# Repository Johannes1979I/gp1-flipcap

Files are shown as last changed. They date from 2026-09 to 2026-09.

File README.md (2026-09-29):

# GP1 FlipCap V6

Tappo antipolvere motorizzato per telescopi newtoniani, comandato da
**INDI / Ekos**. Un motore e un braccio: aprendosi il tappo ruota di **270°**,
scavalca la scatola e si **posa sul tubo**, così il vento non lo fa vibrare.
Riduttore ed elettronica stanno in un'unica scatola stampata, fissata al tubo
con due cinghie a strappo.

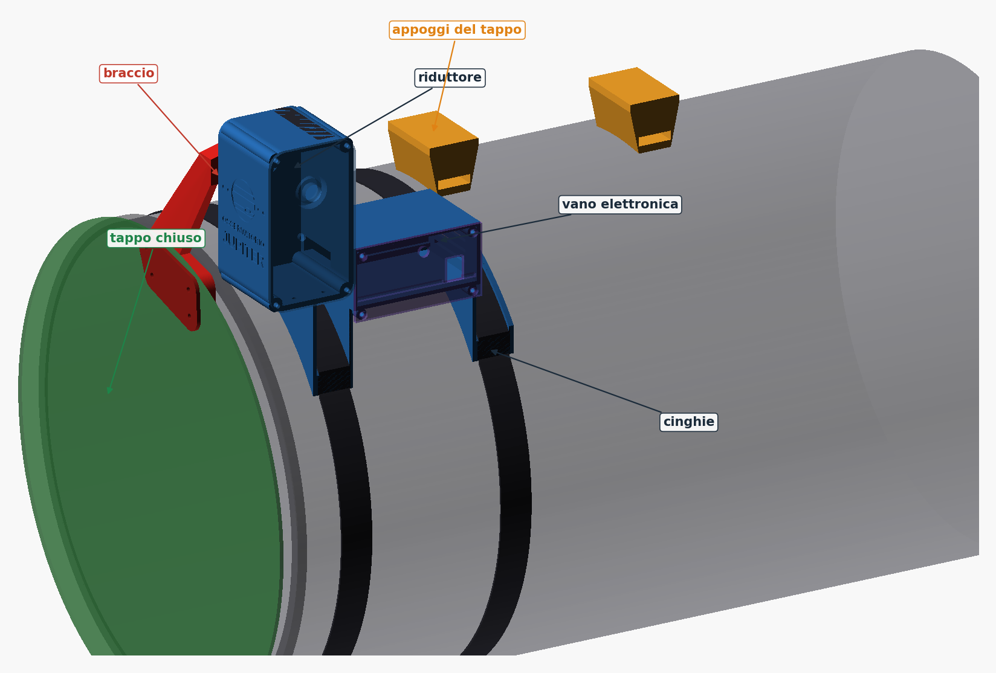
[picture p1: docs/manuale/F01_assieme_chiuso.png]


📘 **[MANUALE_MONTAGGIO_V6.pdf](MANUALE_MONTAGGIO_V6.pdf)**: dal primo pezzo
stampato fino alla configurazione di Ekos, passo per passo, per chi costruisce
da zero.

---

## Caratteristiche

| | |
|---|---|
| Motore | 28BYJ-48 5 V + scheda ULN2003 |
| Riduzione | riduttore interno del 28BYJ + treno stampato 15:1 (modulo 0,8) |
| Corsa | 270°, circa 55 secondi; da aperto il tappo appoggia su due supporti sul tubo |
| Albero di uscita | acciaio Ø6 × 100 mm su due 626ZZ, bloccato da distanziali stampati |
| Finecorsa | 2 sensori Hall A3144 su piastra registrabile, magnete 6×3 su bandierina |
| Elettronica | Arduino Nano + ULN2003 + LM2596 nel vano della scatola, su un vassoio |
| Alimentazione | 12 V del setup; USB verso il PC |
| Fissaggio | due selle e due cinghie a strappo da 25 mm |
| Protocollo | Alnitak Remote Dust Cover, product ID 98 (`indi_flipflat`) |
| Default | tubo Ø362 mm (Sky-Watcher Quattro 300), tappo Ø374 mm, tutto parametrico |
| Stampa | 14 file, circa 600 cm³ di PETG o ASA; più 2 assi di prova facoltativi |
| Logo | Osservatorio Jupiter, inciso sulla faccia anteriore della scatola (`logo=false` per toglierlo) |

Non è un pannello per i flat: copre e scopre, non ha una luce.

## Per cominciare

1. Misura il diametro del tuo tubo (circonferenza ÷ π). Se non è 362 mm,
   rigenera `housing` e `cap_rest` (appendice E del manuale).
2. Stampa i pezzi in `stl/`: sono già orientati per la stampa. PETG o ASA,
   **non PLA**.
3. Procurati viteria, cuscinetti ed elettronica (capitoli 0.4 e 0.5).
4. Per il tappo usa **polipropilene alveolare da 3 mm** (vedi sotto).
5. Segui il manuale nell'ordine: elettronica a banco, riduttore, telescopio.

```bash
openscad -o stl/housing.stl -D 'part="housing"' -D ota_d=355 gp1_flipcap_V6.scad
openscad -o stl/cap_rest.stl -D 'part="cap_rest"' -D ota_d=355 gp1_flipcap_V6.scad
```

## Il tappo deve essere leggero

Il braccio tiene il tappo a circa 27 cm dall'albero e il 28BYJ-48, con questa
riduzione, eroga circa **0,32 N·m**. Il *margine* è il rapporto fra coppia
disponibile e coppia richiesta nel punto peggiore della corsa: **sotto 1 il
tappo non si alza**.

| Disco Ø374 | Massa | Margine |
|---|---|---|
| **Polipropilene alveolare 3 mm** | **53 g** | **1,6** (consigliato) |
| Depron / XPS 6 mm | 26 g | 2,4 (fragile) |
| Forex 1,5 mm | 91 g | 1,1 (al limite) |
| Forex 2 mm | 121 g | 0,85: non si alza |
| Forex 3 mm | 181 g | 0,60: non si alza |

Per un tappo più pesante serve un motore più forte (NEMA 14 o 17).

## File

```
MANUALE_MONTAGGIO_V6.pdf       manuale di costruzione illustrato
gp1_flipcap_V6.scad            modello parametrico: tutti i pezzi e l'assieme
LICENSE / NOTICE               CERN-OHL-S v2
stl/                           i 14 pezzi da stampare, già orientati, più
                               test_shaft e test_pin: assi di prova in
                               plastica, per provare prima dell'acciaio
firmware/
  GP1_FlipCap_V6/              sketch Arduino
  build/                       .hex precompilato per Nano + istruzioni avrdude
docs/
  BOM_meccanica.csv  BOM_elettronica.csv  COLLEGAMENTI.md
  verifica_collisioni.py       verifica geometrica automatica
  VERIFICA_COLLISIONI.txt      risultato della verifica
  genera_figure_manuale.py     render e schemi del manuale
  contenuto_manuale.py         testo del manuale
  genera_manuale_pdf.py        impaginazione del PDF
  genera_dae.py                assieme per SketchUp
  GP1_V6_assieme.dae           assieme COLLADA (SketchUp, Blender, FreeCAD...)
  manuale/                     figure del manuale
  SHA256SUMS.txt               checksum dei file
```

## Il modello

Apri `gp1_flipcap_V6.scad` con OpenSCAD e premi F5: compare l'assieme
completo, con il tubo, il tappo e tutti i pezzi. `cap_angle` muove il tappo
(0 = chiuso, -270 = parcheggiato), gli interruttori `show_*` accendono e
spengono i singoli pezzi. Per esportare un pezzo imposta `part`, premi F6 ed
esporta l'STL: esce già orientato per la stampa. Serve la libreria MCAD, già
inclusa in OpenSCAD. `logo=false` toglie il logo inciso sulla scatola; il
carattere è il Liberation Sans compreso in OpenSCAD, quindi l'STL esce uguale
su ogni PC.

## Firmware

Sketch per Arduino Nano che emula il protocollo Alnitak: full-step a due fasi
con rampa di accelerazione, antirimbalzo sui sensori, limite di passi e di
tempo se un sensore non scatta, bobine spente a motore fermo. Il driver INDI
ripete il comando dopo 30 secondi: il firmware riconosce la ripetizione e la
ignora, e la corsa da 55 secondi finisce regolarmente.

```
arduino-cli 1.3.1 - core arduino:avr 1.8.6 - fqbn arduino:avr:nano
flash 3612/30720 byte (11%) - RAM 261/2048 byte (12%) - 0 errori, 0 warning
```

## Verifica geometrica

```bash
python docs/verifica_collisioni.py
```

Esporta da OpenSCAD tutti i pezzi in posizione di montaggio e controlla sulle
mesh: che ogni STL sia un solido unico, che i pezzi fermi non si
compenetrino, le luci lungo tutta la corsa di 270° (braccio, contropiastra e
disco del tappo contro scatola, coperchi, appoggi e tubo; bandierina contro
sensori) e la posizione di parcheggio. Serve Python con numpy e scipy; impiega
una ventina di minuti.
Risultato attuale in [docs/VERIFICA_COLLISIONI.txt](docs/VERIFICA_COLLISIONI.txt).

## Se hai già stampato pezzi delle versioni precedenti

Il composto e il pignone hanno la stessa geometria dalla V4.1 in poi e si
riusano. L'ingranaggio di uscita si riusa dopo averlo forato: nelle V4.x il
foro del grano cadeva sulla faccia invece che nel mozzo (appendice F del
manuale); il file della V6 ha già il foro giusto. La bandierina della V4.1 ha
la tasca del magnete chiusa dentro il pezzo e va ristampata. Tutto il resto è
nuovo.

Gli ingranaggi della prima versione, prima della V4.1, sono diversi e non
ingranano: l'uscita giusta ha 70 denti e 57,6 mm di diametro esterno. Se i tuoi
non corrispondono, ristampali da `stl/` senza scalarli.

## Licenza

**CERN Open Hardware Licence Version 2 – Strongly Reciprocal** (CERN-OHL-S v2).
Testo completo in [LICENSE](LICENSE), sintesi in [NOTICE](NOTICE).

Puoi usare, modificare e ridistribuire il progetto, anche commercialmente. Se
distribuisci un prodotto basato su questi file o una versione modificata dei
file stessi, devi rendere disponibile la sorgente completa corrispondente
sotto la stessa licenza.

## Avvertenza

Progetto amatoriale fornito **così com'è, senza garanzia**. Le verifiche
geometriche valgono per il modello con i parametri di default: se li cambi,
rilancia la verifica. Chi monta questo meccanismo su un telescopio è
responsabile delle proprie verifiche meccaniche ed elettriche.

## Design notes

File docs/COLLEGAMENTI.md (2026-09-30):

# Collegamenti elettrici - GP1 FlipCap V6

Schema completo nella figura B1 del manuale (`docs/manuale/F12_cablaggio.png`).

## Alimentazione

- 12 V del setup -> fusibile ritardato 1 A (sul cavo) -> presa DC sul coperchio del vano
- presa DC -> IN+ / IN- del convertitore LM2596
- **Regolare l'LM2596 a 5,00 V a vuoto, prima di collegare qualunque altra cosa.**
- OUT+ dell'LM2596 -> morsetto **+5 V**
- OUT- dell'LM2596 -> morsetto **GND**

## Bus +5 V e GND (due WAGO 221-415)

| Morsetto | Cosa ci va |
|---|---|
| +5 V | OUT+ LM2596, + della ULN2003, VCC dei sensori, + del condensatore da 1000 uF |
| GND | OUT- LM2596, - della ULN2003, GND dei sensori, - del condensatore, **GND del Nano** |

Il Nano si alimenta **solo dalla USB**: niente sul suo pin 5V. Il GND in comune
fra Nano e resto del circuito e' obbligatorio.

## Arduino Nano -> ULN2003

- D2 -> IN1
- D3 -> IN2
- D4 -> IN3
- D5 -> IN4

Il 28BYJ-48 si innesta nel connettore bianco a 5 poli della ULN2003.

## Sensori Hall

Visti dal lato della faccia marcata, piedini in basso: VCC, GND, uscita.

- D10 <- uscita del sensore **CLOSED** (sede rivolta verso il bordo anteriore della scatola, lato tappo)
- D11 <- uscita del sensore **OPEN** (sede rivolta verso il fondo della scatola, lato tubo)
- VCC -> +5 V, GND -> GND, 100 nF fra VCC e GND vicino a ogni sensore

I sensori si cablano gia' montati nella piastra (sedi marcate C e O). Tutto
resta incassato sotto il piano su cui passa la bandierina: accanto a ogni sede
c'e' l'incavo del condensatore da 100 nF, e il canale porta piedini, saldature
e fili fino al bordo, da cui i fili escono di lato. Canale e incavo si
riempiono di colla a caldo, rasa al piano.

I due VCC e i due GND si uniscono vicino alla piastra: al vano arrivano
quattro fili (VCC, GND, CLOSED, OPEN) attraverso il passaggio fra riduttore e
vano. Il firmware usa le resistenze di pull-up interne del Nano: il sensore
deve portare il pin a GND quando il magnete gli passa davanti. L'A3144 e'
unipolare: se non scatta, gira il magnete.

## INDI / Ekos

Driver **Flip Flat** (`indi_flipflat`), porta seriale del Nano, 9600 baud.
Il firmware emula il product ID 98 (Remote Dust Cover): nessun pannello
luminoso, solo il tappo. Park = chiudi, Unpark = apri.

La corsa dura circa 55 secondi: dopo 30 secondi il driver ripete il comando e
scrive *Parking cap timed out. Retrying* nel log. E' normale: il firmware
ignora il comando ripetuto e la corsa finisce regolarmente.

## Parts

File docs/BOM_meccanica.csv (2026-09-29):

Quantita | Componente | Dove va / nota
1 | Albero acciaio Ø6 x 100 mm (tondo rettificato) | Albero di uscita. Limare due piccoli piani a 41 e 73 mm dal lato braccio per i grani
2 | Cuscinetto 626ZZ (6x19x6) | Parete sinistra della scatola e coperchio del riduttore; entrano dall'interno
1 | Cuscinetto 625ZZ (5x16x5) | Dentro il lato 42T dell'ingranaggio composto
1 | Vite M5 x 90 a testa cilindrica (DIN 912) + 2 rondelle M5 + dado autobloccante M5 | Perno dell'ingranaggio composto; il dado non va stretto e la vite deve uscirne di qualche filetto (la x 80 e' corta)
1 | Rondella PTFE o nylon M5 spessore 1 mm | Fra distanziale c1 e ingranaggio composto
10 | Inserti filettati a caldo M3 (lunghezza 4-6 mm) | 4 coperchio riduttore; 4 coperchio vano; 2 piede della staffa motore
4 | Viti M3 x 8 testa svasata piana | Coperchio del vano elettronica
8 | Viti M3 x 8 testa cilindrica | 4 coperchio del riduttore; 2 staffa motore (da sotto il fondo della scatola); 2 orecchie del 28BYJ-48 (si filettano da sole nella plastica)
2 | Viti M3 x 16 + rondelle + dadi | Piastra dei sensori; dall'esterno della parete sinistra
1 | Vite M3 x 25 + dado | Morsetto del mozzo del braccio
3 | Grani M3 x 5 | Bandierina del magnete; ingranaggio di uscita; pignone del motore
4 | Viti M4 x 16 + rondelle larghe + dadi M4 | Tappo sul braccio; i dadi vanno nelle sedi sotto la piastra del braccio
4 | Viti autofilettanti 1.7 x 6 (o M1.6) | Arduino Nano sulle colonnine alte
8 | Viti autofilettanti M3 x 6 | ULN2003 e LM2596 sulle colonnine basse
1 | Magnete al neodimio 6 x 3 mm (N35 o superiore) | Tasca della bandierina
4 | Cinghia a strappo (velcro) 25 mm x 1.4 m | 2 per la scatola (sopra le selle); 2 per gli appoggi del tappo
1 | Gomma EVA (crepla) adesiva 2 mm; un foglio A4 | Interno delle selle; sopra e sotto gli appoggi del tappo
1 | Lastra di polipropilene alveolare 3 mm almeno 380 x 380 mm | Disco del tappo Ø374 (il Forex e' troppo pesante per il 28BYJ-48)
- | PETG o ASA; circa 500 g | Tutti i pezzi stampati (non PLA)

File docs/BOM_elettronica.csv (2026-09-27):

Quantita | Componente | Nota
1 | Arduino Nano compatibile (ATmega328P 5 V 16 MHz) | Va bene un clone con CH340; mini-USB o USB-C
1 | Motore 28BYJ-48 versione 5 V | Di solito venduto insieme alla scheda ULN2003
1 | Scheda driver ULN2003 per 28BYJ-48 | Il motore si innesta nel connettore bianco a 5 poli
1 | Convertitore buck LM2596 (modulo 43 x 21 mm) | Regolato a 5.0 V a vuoto prima di collegare qualunque cosa
2 | Sensore Hall A3144 o AH3144E (TO-92) | Interruttore unipolare: risponde a una sola faccia del magnete
2 | Condensatore ceramico 100 nF | Fra VCC e GND di ogni sensore; vicino al corpo
1 | Condensatore elettrolitico 1000 uF 10-16 V | Sul bus +5 V; attenzione alla polarita'
1 | Presa DC 5.5 x 2.1 da pannello tipo DC-022B | Foro da 8 mm nel coperchio del vano
1 | Portafusibile volante + fusibile ritardato 1 A | Sul cavo dei 12 V
2 | Morsetto a leva WAGO 221-415 (5 vie) | Bus +5 V e bus GND
1 | Cavo USB per il Nano | Dal Nano al PC o mini PC del setup
- | Cavetti Dupont femmina-femmina; filo 0.25-0.5 mm2; guaina termorestringente

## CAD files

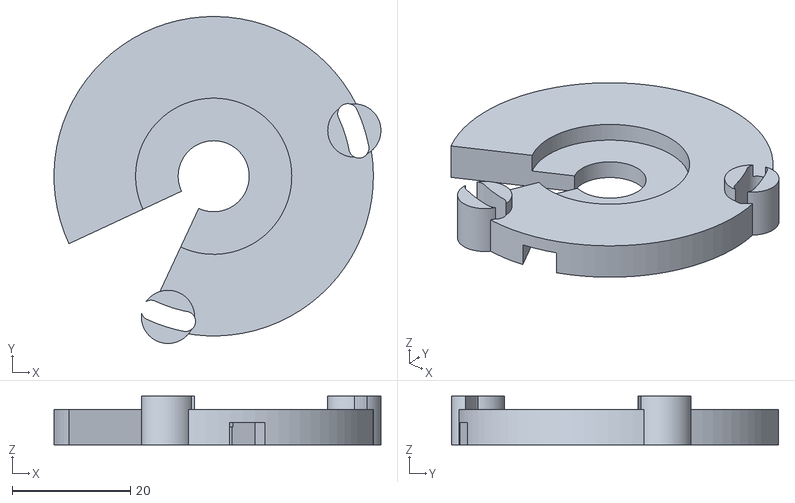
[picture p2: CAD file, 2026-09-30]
stl/hall_plate.stl
55.3 x 55.3 x 8.20

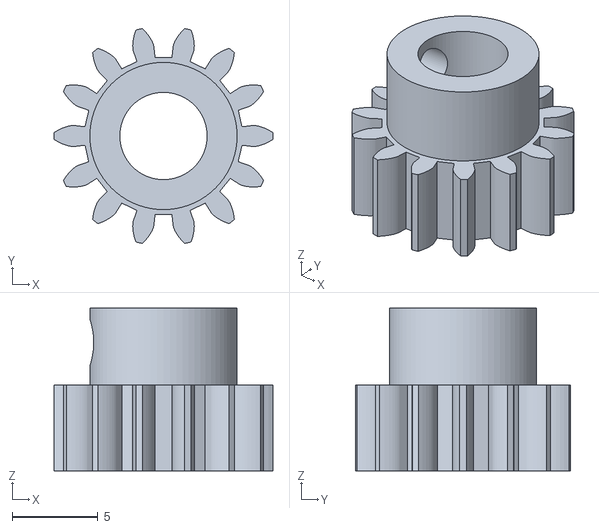
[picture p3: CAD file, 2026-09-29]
stl/motor_pinion.stl
12.8 x 12.6 x 9.50

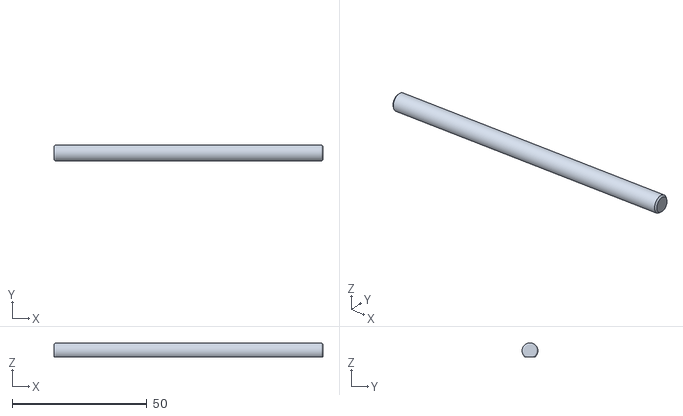
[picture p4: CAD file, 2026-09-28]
stl/test_shaft.stl
100.0 x 5.90 x 5.30

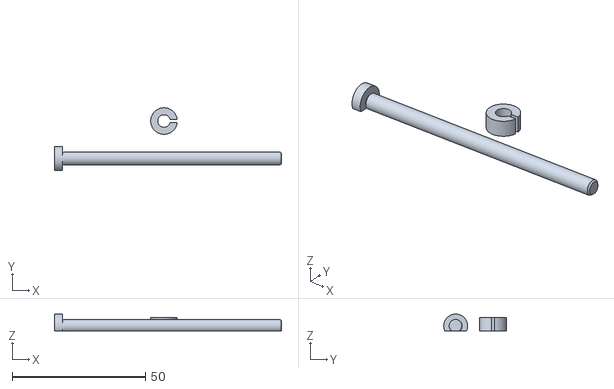
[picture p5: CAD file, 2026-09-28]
stl/test_pin.stl
85.2 x 23.5 x 6.35

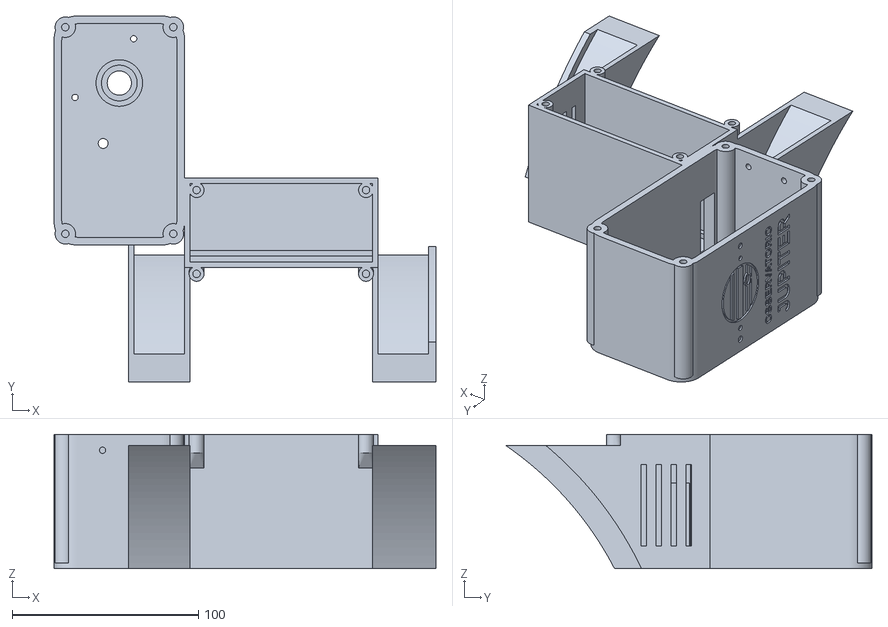
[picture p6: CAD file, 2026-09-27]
stl/housing.stl
205.0 x 196.6 x 72.0

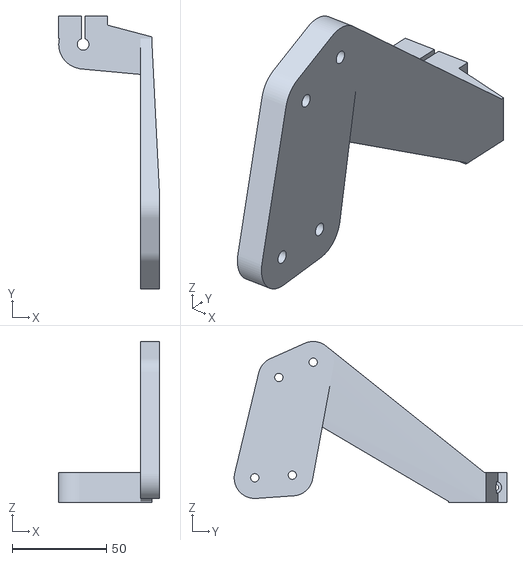
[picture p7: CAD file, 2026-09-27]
stl/mono_arm.stl
53.5 x 145.0 x 85.6

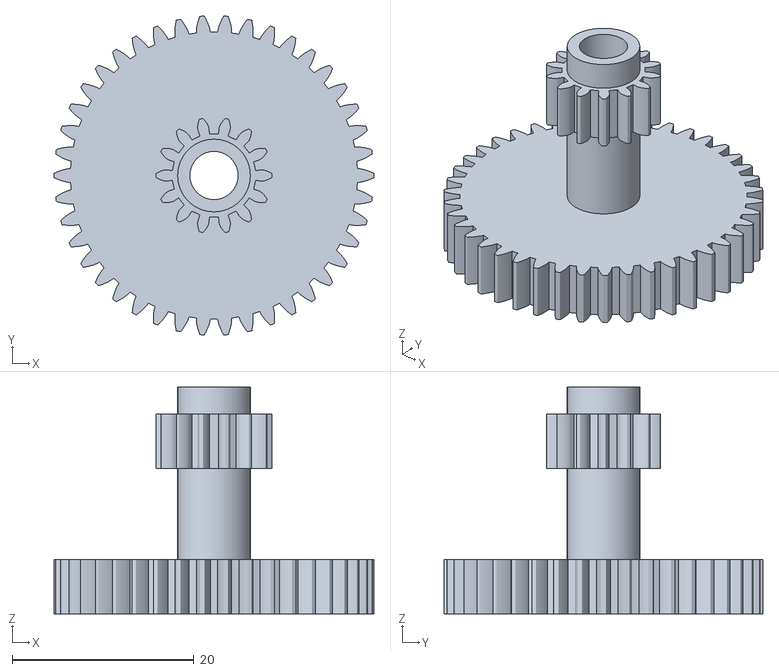
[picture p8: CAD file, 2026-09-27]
stl/compound_gear.stl
35.2 x 35.1 x 25.0

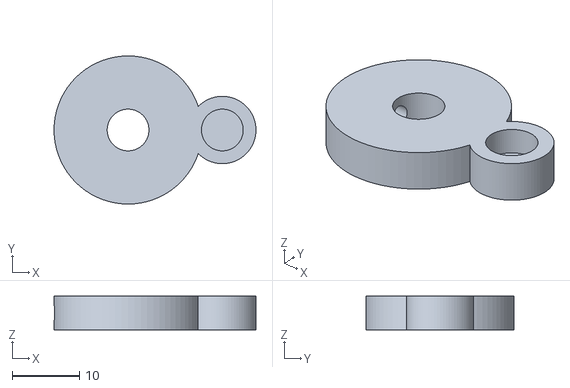
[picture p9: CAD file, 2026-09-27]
stl/magnet_flag.stl
30.0 x 22.0 x 5.00

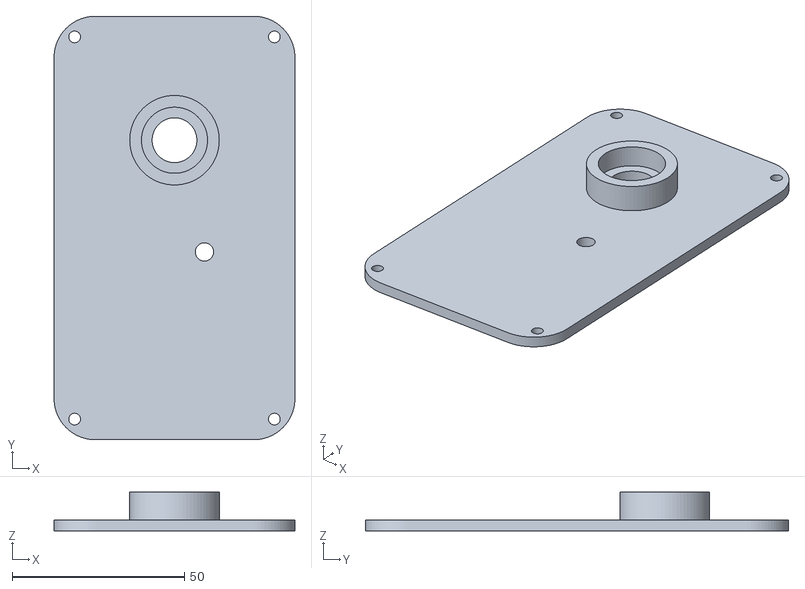
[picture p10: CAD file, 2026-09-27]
stl/cover.stl
70.0 x 123.0 x 11.2

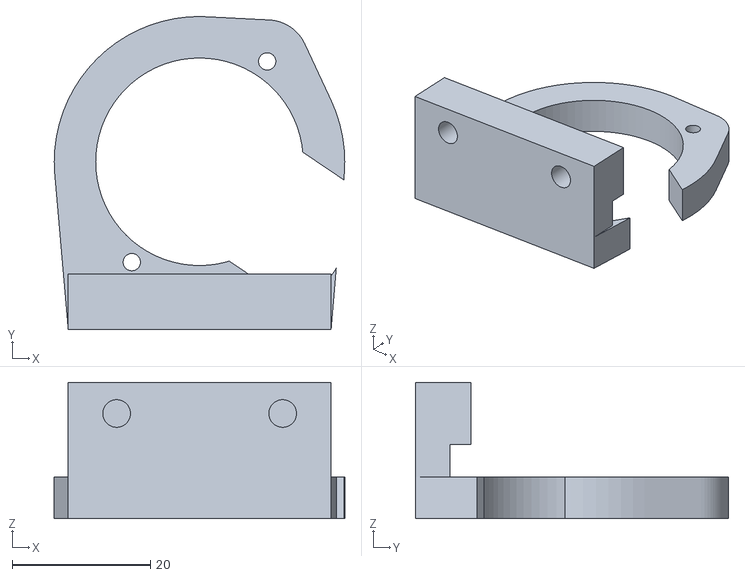
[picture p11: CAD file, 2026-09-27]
stl/motor_bracket.stl
42.0 x 45.2 x 19.7

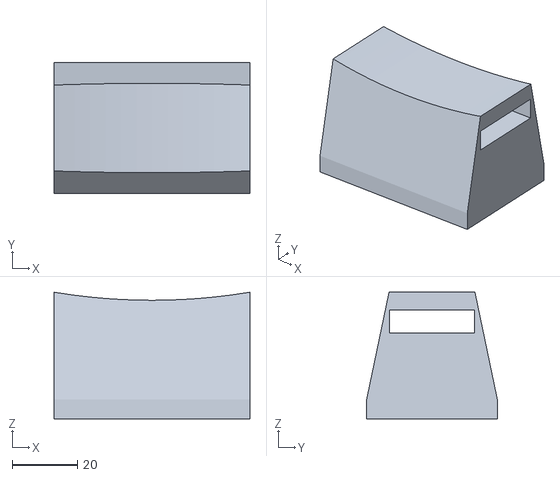
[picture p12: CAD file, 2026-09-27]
stl/cap_rest.stl
60.0 x 40.0 x 38.8

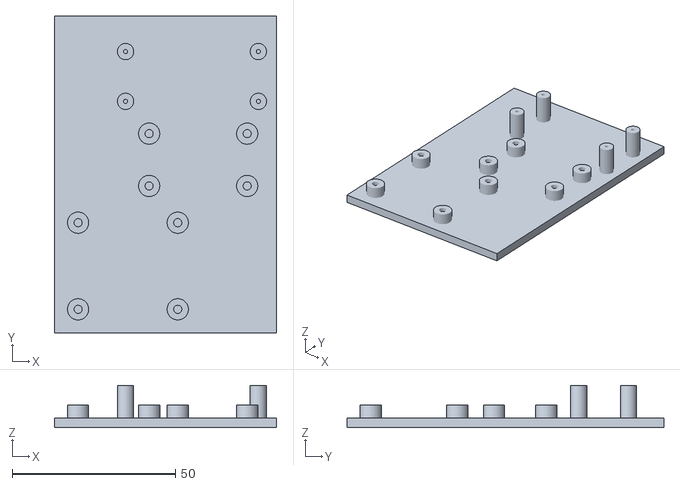
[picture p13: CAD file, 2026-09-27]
stl/bay_tray.stl
68.0 x 97.0 x 13.0

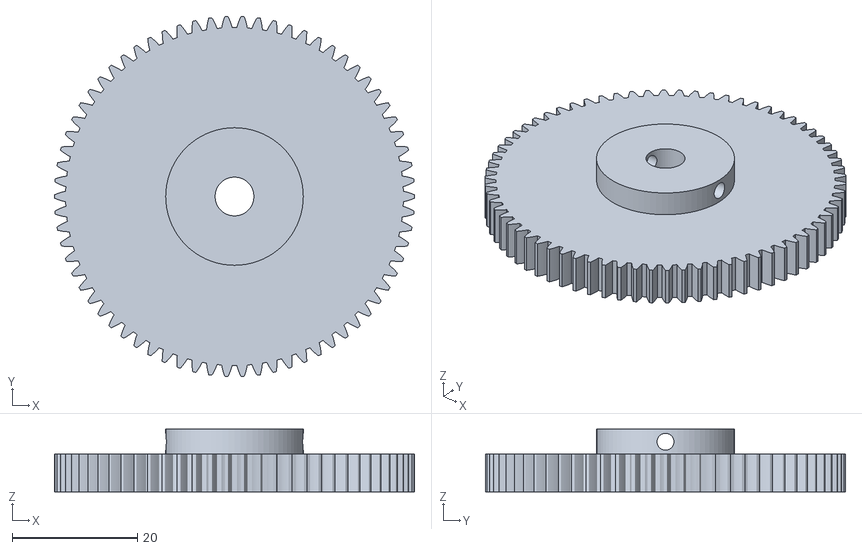
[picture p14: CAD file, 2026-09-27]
stl/output_gear.stl
57.6 x 57.6 x 10.0

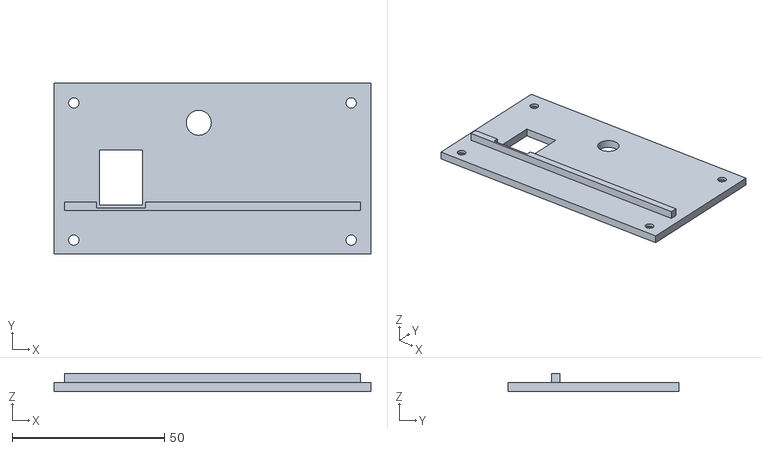
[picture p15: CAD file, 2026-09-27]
stl/bay_lid.stl
104.0 x 56.0 x 6.00

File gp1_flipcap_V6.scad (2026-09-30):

// SPDX-License-Identifier: CERN-OHL-S-2.0
// Copyright (C) 2026 Johannes1979I
/*
 =============================================================================
  GP1 FlipCap V6
  Tappo motorizzato per telescopi newtoniani, comandato da INDI / Ekos.
  Un motore, un braccio, ribaltamento di 270 gradi: da aperto il tappo si
  appoggia sul tubo. Riduttore ed elettronica nella stessa scatola.
 =============================================================================

  COME SI USA
  - Apri il file in OpenSCAD e premi F5: compare l'assieme completo.
    La prima anteprima impiega qualche decina di secondi perche' i pezzi
    complessi vengono calcolati per intero (render()); poi restano in cache.
  - cap_angle muove il tappo: 0 = chiuso, -270 = parcheggiato sul tubo.
  - Gli interruttori show_* accendono e spengono i singoli pezzi.
  - logo=false toglie il logo dell'Osservatorio Jupiter inciso sulla scatola.
  - Per esportare un pezzo: imposta part (elenco sotto), premi F6 e poi
    File > Export > STL. Il pezzo esce gia' orientato per la stampa.
  - Da riga di comando:
        openscad -o stl/housing.stl -D 'part="housing"' gp1_flipcap_V6.scad

  SISTEMA DI RIFERIMENTO
    Z = asse ottico. Il tubo si estende verso Z negativo, la bocca e' a Z=0.
    Y = verso l'alto nel piano della bocca, dal lato in cui sta la scatola.
    X = di lato; la scatola sta a X positivo, il braccio fra tubo e scatola.
    L'albero di uscita, cioe' la cerniera del tappo, e' parallelo a X.

  LIBRERIE
    Serve MCAD (involute_gears.scad), inclusa nell'installazione di OpenSCAD.
    MCAD stampa in console alcuni avvisi "DEPRECATED" su assign() e child():
    vengono dalla libreria, non da questo file, e non hanno effetto.
*/

use <MCAD/involute_gears.scad>
$fn=72;

// =============================================================================
//  COSA MOSTRARE O ESPORTARE
// =============================================================================
part="assembly";
// assembly
// housing | cover | motor_bracket | hall_plate | spacers |
// bay_lid | bay_tray |
// output_gear | compound_gear | motor_pinion | magnet_flag |
// mono_arm | cap_backplate | cap_rest
// test_shaft | test_pin      (facoltativi: assi di prova in plastica, solo orient="print")

orient="print";   // print  = orientato per la stampa (e' quello che sta in stl/)
                  // placed = nella posizione di montaggio (per le verifiche)

cap_angle=0;      // 0 = chiuso, open_angle = parcheggiato

show_ota=true;      show_cap=true;      show_housing=true;   show_cover=true;
show_bay_lid=true;  show_bay_tray=true; show_boards=true;    show_bracket=true;
show_motor=true;    show_gears=true;    show_shaft=true;     show_spacers=true;
show_hall=true;     show_flag=true;     show_arm=true;       show_backplate=true;
show_rests=true;

// =============================================================================
//  TUBO E TAPPO
// =============================================================================
ota_d=362;            // diametro ESTERNO del tubo: circonferenza / pi greco
ota_clearance=1.2;    // gioco fra selle e tubo (lo riempie l'EVA)
cap_d=374;            // diametro del disco del tappo: ~12 mm piu' del tubo
cap_thickness=3;      // spessore del disco. Decide la quota delle piazzole
                      // del braccio: se lo cambi rigenera mono_arm e cap_rest
open_angle=-270;      // corsa del tappo

// =============================================================================
//  CERNIERA E BRACCIO
// =============================================================================
hinge_y=264;          // quota dell'albero di uscita dall'asse ottico. Da
                      // parcheggiato il piano del tappo sta a hinge_y-arm_dz
                      // = 222 mm, sopra la scatola dell'elettronica (213)
hinge_z=-25;          // l'albero sta 25 mm dietro la bocca del tubo
arm_x=68;             // posizione del mozzo del braccio sull'albero
arm_dz=42;            // piano medio del tappo rispetto all'albero (chiuso: Z=+17)
arm_w=16;             // larghezza della colonna del braccio
plate_h=10;           // spessore della piastra che regge il tappo
rest_z=[-215,-380];   // dove vanno gli appoggi del tappo, lungo il tubo. Il primo
                      // sta dietro la cinghia posteriore e fuori dalla contropiastra
rest_pad=2;           // EVA incollata sopra ogni appoggio

// =============================================================================
//  RIDUTTORE: 28BYJ-48 + treno stampato 14/42 x 14/70 = 15:1, modulo 0,8
// =============================================================================
gear_module=0.8;
pressure_angle=20;
backlash=0.22;
gear_t=6;
motor_teeth=14;
compound_big_teeth=42;
compound_small_teeth=14;
final_teeth=70;

stage1_center=(motor_teeth+compound_big_teeth)*gear_module/2;     // 22,4
stage2_center=(compound_small_teeth+final_teeth)*gear_module/2;   // 33,6

// Direzioni nel piano YZ, in gradi da "verso il basso" (-Y) ruotando verso
// la bocca del tubo (+Z). Scelte con una ricerca numerica per dare al 28BYJ
// reale (albero eccentrico) almeno 3,5 mm di luce da pareti e ingranaggi.
compound_angle=15;    // asse del composto visto dall'asse di uscita
motor_angle=-13;      // albero motore visto dall'asse del composto
function yz_dir(a)=[-cos(a),sin(a)];

hinge_yz=[hinge_y,hinge_z];
compound_yz=hinge_yz+stage2_center*yz_dir(compound_angle);
motor_yz=compound_yz+stage1_center*yz_dir(motor_angle);

final_x=5;            // posizioni lungo X delle ruote rispetto a box_x
compound_small_x=5;
compound_big_x=21;
motor_pinion_x=21;

// =============================================================================
//  MOTORE 28BYJ-48
//  L'albero NON e' al centro della carcassa: e' spostato di 8 mm, dalla parte
//  opposta al cappuccio azzurro da cui escono i fili. Le due orecchie stanno
//  sulla retta per il centro della carcassa, perpendicolare a quello spostamento.
// =============================================================================
byj_offset=8;
byj_can_d=28;
byj_can_h=19;
byj_hole_span=35;     // interasse dei fori delle orecchie
byj_ear_w=7;
byj_ear_t=1;
byj_can_angle=-56;    // direzione albero -> centro carcassa (verso il basso e il retro)
byj_face_x=139.3;     // faccia delle orecchie dal lato albero. Il collarino
                      // (1,5 mm) arriva a 140,8, il pignone parte da 141

can_yz=motor_yz+byj_offset*yz_dir(byj_can_angle);
byj_w=yz_dir(byj_can_angle);                 // verso il cappuccio dei fili
byj_u=[byj_w[1],-byj_w[0]];                  // direzione delle orecchie
byj_ears=[can_yz+byj_hole_span/2*byj_u, can_yz-byj_hole_span/2*byj_u];

// =============================================================================
//  SCATOLA DEL RIDUTTORE (estremi esterni)
// =============================================================================
box_x0=84;  box_x1=156;     // parete sinistra .. lato aperto (coperchio)
box_y0=177; box_y1=300;
box_z0=-60; box_z1=10;
wall=4;
corner_r=12;
cover_t=3.2;
box_x=(box_x0+box_x1)/2;    // 120, riferimento per le posizioni delle ruote

cav_x0=box_x0+wall;         // 88
cav_y0=box_y0+wall; cav_y1=box_y1-wall;
cav_z0=box_z0+wall; cav_z1=box_z1-wall;

// =============================================================================
//  ALBERI, CUSCINETTI, DISTANZIALI
//  I due 626ZZ entrano dall'INTERNO e battono su un labbro esterno. I
//  distanziali stampati li caricano verso l'esterno: l'albero resta
//  bloccato in entrambi i versi senza anelli elastici.
// =============================================================================
output_shaft_d=6;
shaft_len=100;              // albero 6 x 100 mm
bearing_od=19.2;            // 626ZZ, 19 mm nominali
bearing_w=6;
bearing_lip=2.5;            // labbro che trattiene il cuscinetto
bearing_lip_hole=13;        // tocca solo l'anello esterno
left_seat_x0=box_x0+bearing_lip;                 // 86,5
left_seat_x1=left_seat_x0+bearing_w+0.2;         // 92,7
cover_seat_x1=box_x1+cover_t-bearing_lip-2.5;    // 154,2
cover_seat_x0=cover_seat_x1-bearing_w-0.2;       // 148

intermediate_shaft_d=5.3;   // perno M5
compound_bearing_od=16.2;   // 625ZZ
motor_shaft_d=5.1;          // foro scorrevole: il pignone lo tiene il grano
ptfe_washer_t=1.0;          // rondella PTFE o nylon M5 fra distanziale e composto

spacer_od=8.5;              // distanziali sull'albero da 6
cspacer_od=8;               // distanziali sul perno M5
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

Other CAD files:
stl/cap_backplate.stl
stl/spacers.stl

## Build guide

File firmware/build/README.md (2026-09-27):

# Binario precompilato

`GP1_FlipCap_V6.ino.hex` corrisponde al sorgente in
`firmware/GP1_FlipCap_V6/`, compilato per **Arduino Nano (ATmega328P)**.

```
arduino-cli 1.3.1 - core arduino:avr 1.8.6 - avr-gcc 7.3.0-atmel3.6.1-arduino7
fqbn: arduino:avr:nano
flash: 3612 byte su 30720 (11%)
RAM:    261 byte su  2048 (12%)
0 errori, 0 warning nello sketch
```

Serve a chi vuole caricare il firmware senza installare l'IDE Arduino, per
esempio con avrdude:

```
avrdude -c arduino -p m328p -P COM3 -b 115200 -U flash:w:GP1_FlipCap_V6.ino.hex:i
```

Se il Nano ha il bootloader vecchio (quasi tutti i cloni con CH340), usa
`-b 57600`. Al posto di `COM3` metti la porta del tuo Nano
(`/dev/ttyUSB0` su Linux).

**Se modifichi il firmware, ricompila e rigenera questo file**, altrimenti
resta indietro rispetto al sorgente:

```
arduino-cli compile --fqbn arduino:avr:nano --output-dir firmware/build firmware/GP1_FlipCap_V6
```

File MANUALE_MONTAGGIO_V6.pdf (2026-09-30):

# GP1 FlipCap V6

## Manuale di costruzione

Tappo motorizzato a ribaltamento per telescopi newtoniani,

## comandato da INDI / Ekos


Cosa stai per costruire. Un tappo antipolvere che si apre e si chiude da solo quando lo comanda il software di acquisizione. Un solo motore e un solo braccio: aprendosi, il tappo ruota di 270 gradi, scavalca la scatola e si posa sul tubo, così il vento non lo fa vibrare. Riduttore ed elettronica stanno in un'unica scatola stampata, fissata al tubo con due cinghie a strappo. Il progetto è parametrico: diametro del tubo, del tappo e posizioni si cambiano in un file di testo.

GP1 FlipCap V6 - Manuale di costruzione | pag. 2

Quote in mm. Misura il diametro reale del tuo tubo prima di stampare la scatola.

# Indice

Capitolo | Contenuto
0. Il progetto in breve | come funziona, pezzi da stampare, viteria, elettronica, attrezzi, materiale del tappo, adattamento al proprio tubo
A. Preparazione | pulizia dei pezzi, prove a secco, inserti filettati
B. Elettronica | alimentazione, vassoio, cablaggio, firmware, prova a banco
C. Riduttore | cuscinetti, sensori, albero, motore, ingranaggi, taratura, chiusura
D. Sul telescopio | cinghie, braccio, tappo, appoggi, collaudo, Ekos
Appendici | comandi seriali, coppia e peso del tappo, diagnostica, limiti verificati, rigenerare i pezzi, chi ha già pezzi di versioni precedenti, assi di prova in plastica

L'ordine dei passi conta. Alcune viti non si raggiungono più dopo aver montato altri pezzi, e i sensori si tarano girando l'albero a mano, cosa possibile solo prima di montare il pignone del motore. Segui i passi nell'ordine in cui sono scritti: elettronica a banco, poi riduttore, poi telescopio.

Questo progetto è open hardware. Licenza CERN-OHL-S v2: puoi usarlo, modificarlo e ridistribuirlo, anche commercialmente, a patto di pubblicare la sorgente delle tue modifiche con la stessa licenza. È fornito così com'è, senza alcuna garanzia: chi lo monta sul proprio telescopio è responsabile delle proprie verifiche.

# 0. Il progetto in breve

come funziona e cosa serve prima di cominciare

## 0.1 Come funziona

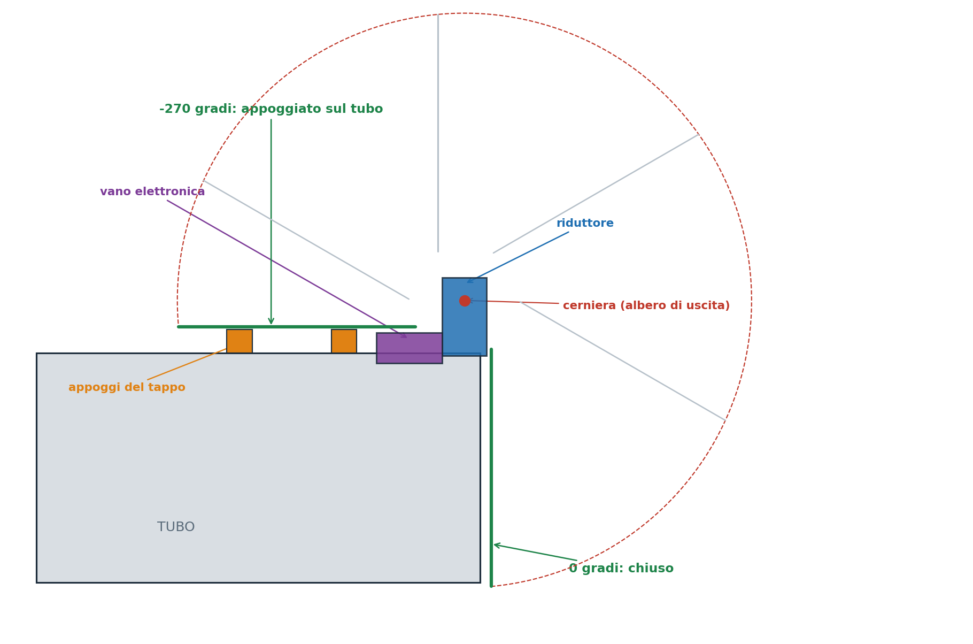
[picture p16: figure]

FIG. 0.1 - vista di fianco, in scala. Il tappo ruota di 270 gradi attorno all'albero e si posa sul tubo; la linea tratteggiata è la traiettoria del suo bordo esterno
Il tappo è avvitato a un braccio che sta sull'albero di uscita di un piccolo riduttore. Un motore passo-passo 28BYJ-48 muove l'albero attraverso una riduzione stampata 15:1. A tappo chiuso il disco sta davanti alla bocca del tubo; aprendo, ruota di 270 gradi, passa sopra la scatola e si appoggia su due supporti fissati al tubo. Due sensori a effetto Hall leggono un magnete che gira con l'albero e dicono al firmware quando fermarsi.
Voce | Valore
Motore | 28BYJ-48 da 5 V con scheda driver ULN2003
Riduzione | riduttore interno del 28BYJ + treno stampato 15:1 (modulo 0,8: 14T->42T, 14T->70T)
Corsa | 270 gradi in circa 55 secondi
Albero di uscita | acciaio 6 x 100 mm su due cuscinetti 626ZZ
Finecorsa | 2 sensori Hall A3144 su una piastra, magnete 6 x 3 mm su una bandierina solidale all'albero
Elettronica | Arduino Nano, ULN2003, convertitore LM2596, tutto nel vano della scatola
Alimentazione | 12 V (quelli del setup), circa 0,3 A durante il movimento, zero a motore fermo
Fissaggio | due selle curve e due cinghie a strappo da 25 mm
Software | protocollo Alnitak (product ID 98), driver INDI indi_flipflat; compatibile con qualunque programma che comandi un Alnitak

Voce | Valore
Misure di default | tubo Ø362 mm, tappo Ø374 mm: entrambe parametriche, vedi 0.8

Non è un pannello per i flat. Il product ID 98 è un dust cover: copre e scopre, e basta. Non ha una luce. Il tappo inoltre resta a circa 12 mm dalla bocca del tubo: protegge dalla polvere e dalla rugiada ma non è a tenuta di luce. Per i dark copri il tubo come fai adesso, o vedi il consiglio del passo D4.

## 0.2 Pezzi da stampare

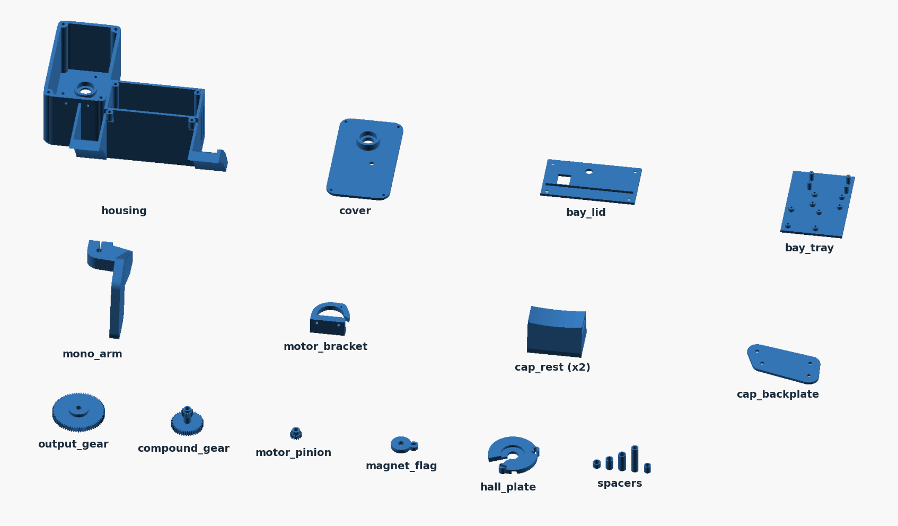
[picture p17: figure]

FIG. 0.2 - i pezzi da stampare, in scala fra loro, come vanno sul piatto Tutti i file sono in stl/ e sono già orientati per la stampa: aprili nello slicer e non ruotarli. Materiale totale circa 610 cm3, cioè intorno ai 460 g di PETG con i parametri qui sotto.

File | Q.tà | Cos'è | Stampa
housing | 1 | scatola: riduttore, vano elettronica, due selle; logo inciso sulla faccia anteriore | sul piatto la parete sinistra. Senza supporti; se la stampante fatica sugli sbalzi, supporti solo sotto le due selle
cover | 1 | coperchio del riduttore, con la sede del secondo 626ZZ | faccia esterna sul piatto
motor_bracket | 1 | staffa del motore | già orientata, nessun supporto
hall_plate | 1 | piastra dei due sensori | sedi dei sensori sul piatto
spacers | 1 | cinque distanziali (s1, s2, s3, c1, c2) | in piedi; stampali al 100% di riempimento
bay_lid | 1 | coperchio del vano, con presa 12 V e foro USB | faccia esterna sul piatto
bay_tray | 1 | vassoio delle schede | colonnine verso l'alto
output_gear | 1 | ingranaggio di uscita 70T | sul lato senza mozzo
compound_gear | 1 | ingranaggio composto 42T + 14T | 42T sul piatto
motor_pinion | 1 | pignone del motore 14T | sul lato senza mozzo

File | Q.tà | Cos'è | Stampa
magnet_flag | 1 | bandierina del magnete | in piano
mono_arm | 1 | braccio del tappo | fianco del mozzo sul piatto; supporti sotto la piastra del tappo
cap_backplate | 1 | contropiastra del tappo | in piano
cap_rest | 2 | appoggi del tappo sul tubo | faccia d'appoggio sul piatto
test_shaft | 1 | facoltativo: albero di prova in plastica | sdraiato, come nel file; vedi sotto
test_pin | 1 | facoltativo: perno di prova del composto, con la ghiera | sdraiato, come nel file; vedi sotto

L'housing è grande. Occupa 205 x 197 mm sul piatto e 72 mm di altezza: ci sta su un piatto da 220 x 220 mm. Conviene lanciarlo per primo e stampare il resto mentre gira.

Il logo. Sulla faccia anteriore del riduttore è inciso per 1 mm il logo dell'Osservatorio Jupiter. In stampa quella faccia è verticale e il logo esce nitido, senza supporti. Per farlo risaltare passa vernice acrilica bianca nell'incisione e togli subito l'eccesso con un panno appena umido. Per una scatola liscia: logo=false (appendice E).

Assi di prova (facoltativi). test_shaft e test_pin sono l'albero d'acciaio e la vite M5 in versione stampata: servono a montare e provare il riduttore prima di tagliare l'albero e di comprare la vite. Come stamparli, cosa si può provare con loro e cosa no: appendice G.

## 0.3 Materiale e impostazioni

Gruppo | Materiale | Layer | Perimetri | Riempimento
housing, coperchi, staffa, braccio, appoggi | PETG o ASA | 0,20 mm | 4 | 30-40%
ingranaggi | PETG, ASA o PA | 0,12-0,16 mm | 5 o più | 50-100%
piastra sensori, bandierina, contropiastra, vassoio | PETG o ASA | 0,20 mm | 3 | 30%
distanziali | PETG o ASA | 0,15 mm | tutti | 100%
assi di prova (facoltativi, appendice G) | PLA | 0,12 mm | 8 | 100% rettilineo

Il PLA non va bene per i pezzi definitivi. La scatola sta al sole del pomeriggio prima della sessione e il motore scalda: il PLA si deforma già a 55-60 gradi. Usa PETG o ASA. Il PLA va bene solo per gli assi di prova, che non restano sul telescopio.

## 0.4 Viteria e minuteria

Q.tà | Componente | Dove va
1 | Albero in acciaio Ø6 x 100 mm (tondo rettificato) | albero di uscita
2 | Cuscinetto 626ZZ (6 x 19 x 6) | parete della scatola e coperchio
1 | Cuscinetto 625ZZ (5 x 16 x 5) | dentro il 42T del composto
1 | Vite M5 x 90 a testa cilindrica + 2 rondelle + dado autobloccante M5 | perno del composto (la x 80 è corta: il dado non si blocca)
1 | Rondella PTFE o nylon M5, spessore 1 mm | fra distanziale c1 e composto
10 | Inserti filettati a caldo M3 (lunghezza 4-6 mm) | 4 coperchio riduttore, 4 coperchio vano, 2 staffa motore
4 | Viti M3 x 8 a testa svasata piana | coperchio del vano
8 | Viti M3 x 8 a testa cilindrica | 4 coperchio del riduttore, 2 staffa del motore (dal fondo della scatola), 2 orecchie del motore (si filettano da sole nella plastica)
2 | Viti M3 x 16 + rondelle + dadi | piastra sensori, dalla parete sinistra
1 | Vite M3 x 25 + dado | morsetto del mozzo del braccio
3 | Grani M3 x 5 | bandierina, ingranaggio di uscita, pignone del motore
4 | Viti M4 x 16 + rondelle larghe + dadi M4 | tappo sul braccio
4 | Viti autofilettanti 1,7 x 6 (o M1,6) | Arduino Nano sulle colonnine
6-8 | Viti autofilettanti M3 x 6 | ULN2003 e LM2596 sulle colonnine
1 | Magnete al neodimio 6 x 3 mm (N35 o più) | bandierina
4 | Cinghie a strappo (velcro) 25 mm x 1,4 m | 2 per la scatola, 2 per gli appoggi
1 | Gomma EVA (crepla) adesiva 2 mm, un foglio A4 | selle e appoggi
1 | Lastra per il tappo, almeno 380 x 380 mm | vedi 0.7

## 0.5 Elettronica

Q.tà | Componente | Nota
1 | Arduino Nano (ATmega328P, 5 V) | va bene un clone con CH340
1 | Motore 28BYJ-48 5 V con scheda ULN2003 | di solito si vendono insieme
1 | Convertitore LM2596 (modulo 43 x 21 mm) | 12 V -> 5,0 V
2 | Sensore Hall A3144 (o AH3144E) | interruttore unipolare, contenitore TO-92
2 | Condensatore ceramico 100 nF | uno per sensore
1 | Condensatore elettrolitico 1000 uF 10-16 V | sul +5 V
1 | Presa DC 5,5 x 2,1 da pannello, tipo DC-022B | foro da 8 mm
1 | Portafusibile volante con fusibile ritardato 1 A | sul cavo dei 12 V
2 | Morsetti a leva WAGO 221-415 (5 vie) | bus +5 V e bus GND
- Cavetti Dupont femmina-femmina, filo 0,25-0,5 mm2, guaina | termorestringente
1 | Cavo USB per il Nano | fino al PC o al mini PC del setup

## 0.6 Attrezzi

Saldatore e stagno · saldatore con punta per inserti (o la punta normale pulita) · chiavi a brugola 1,5 / 2 / 2,5 / 3 / 4 mm · chiave da 5,5, 7 e 8 mm · piccola lima piatta e lima tonda · cutter e riga · multimetro · metro da sarto · trapano con punta da 4,5 mm (fori del tappo) · un PC con l'IDE Arduino.

## 0.7 Il tappo: che materiale usare

È la scelta che pesa di più su tutto il progetto. Durante la corsa il braccio deve sollevare il tappo tenendolo a circa 27 cm dall'albero, e il 28BYJ-48 con la riduzione stampata eroga circa 0,32 N·m. Il margine in tabella è il rapporto fra coppia disponibile e coppia richiesta nel punto peggiore della corsa, compresi braccio, contropiastra e viti: sotto 1 il tappo non si alza, sotto 1,3 funziona ma senza riserva.

Disco Ø374 | Massa del disco | Coppia richiesta | Margine | Giudizio
Polipropilene alveolare 3 mm | 53 g | 0,21 N·m | 1,6 | consigliato: leggero, rigido, impermeabile, si taglia col cutter
Depron / XPS 6 mm | 26 g | 0,14 N·m | 2,4 | il più leggero, ma si ammacca con un dito
Forex 1,5 mm | 91 g | 0,30 N·m | 1,1 | al limite; flette molto
Forex 2 mm | 121 g | 0,38 N·m | 0,85 | non si alza
Forex 3 mm | 181 g | 0,54 N·m | 0,60 | non si alza

Usa il polipropilene alveolare da 3 mm. È il materiale dei cartelli elettorali e delle scatole da trasloco in plastica (Polionda, Akylux): pesa circa 480 g al metro quadro, non teme l'umidità e si taglia con il cutter. Orienta i canali interni lungo la linea che va dall'attacco del braccio al bordo opposto: è la direzione in cui il disco lavora a flessione. Il Forex, anche sottile, con questo motore non funziona: serve un motore più forte (NEMA 14 o 17).

Qualunque cosa aggiungi al tappo (guarnizioni, maniglie, adesivi) va contata: 10 g sul bordo del disco tolgono circa 0,1 al margine.

## 0.8 Adattare il progetto al proprio tubo

Gli STL sono generati per un tubo da 362 mm di diametro esterno (Sky-Watcher Quattro 300) e un tappo da 374 mm. Misura il tuo tubo nel punto dove andrà la scatola: gira attorno al tubo un metro da sarto, leggi la circonferenza e dividi per 3,1416. Su un tubo grande è molto più preciso del calibro.

Differenza dal valore di default | Cosa fare
da -3 a +1 mm | niente: l'EVA sotto le selle assorbe la differenza
oltre | rigenera housing e cap_rest con il tuo diametro (appendice E). Il tappo va tagliato circa 12 mm più grande del tubo

# Parte A - Preparazione dei pezzi

pulizia, prove a secco, inserti filettati

Tre regole da qui in avanti. 1. Non alimentare il motore dal Nano o dalla USB: prende i 5 V dal convertitore.
2. Non collegare niente al convertitore prima di averlo regolato a 5,0 V: un LM2596 nuovo esce spesso a 12 V e brucia Nano e sensori in un colpo solo. 3. Quando il pignone è montato, non girare più il braccio a mano: fra motore e albero c'è una riduzione di quasi 1000:1 e si rompono i denti.
A1 | Pulire i pezzi e fare le prove a secco • Togli supporti e sbavature. Passa una lima tonda nei fori dove entrano alberi e perni. • Cuscinetti: il 626ZZ deve entrare nella sede della parete e in quella del coperchio spinto con il pollice, senza martello. Il 625ZZ deve entrare nella sede del lato 42T dell'ingranaggio composto. Se sono troppo stretti carteggia la sede, non forzare: la plastica si crepa. • Albero da 6 mm: deve scorrere senza gioco nei distanziali s1, s2, s3, nella bandierina e nell'ingranaggio di uscita. • Perno M5: deve scorrere nei distanziali c1 e c2 e nell'ingranaggio composto. • Pignone: deve scorrere sull'albero del motore; lo blocca il grano M3 del mozzo. Se riusi il pignone della V4.1, che non ha grano, lima il suo foro a D finché entra a pressione sull'albero. Non montarlo ancora sul motore.
A2 | Inserti filettati a caldo Ti serve: 10 inserti filettati M3, saldatore, un pezzo di metallo piano • Sono dieci: quattro nei bossoli agli angoli del riduttore, quattro nei bossoli del vano elettronica (due dentro in alto, due sotto il fondo) e due sotto il piede della staffa del motore. • Saldatore a circa 220 gradi. Appoggia l'inserto sul foro, scaldalo e lascialo scendere col suo peso, tenendo il saldatore dritto. Fermati quando è a filo, poi appoggia subito una superficie piana fredda per allinearlo. • Se un inserto va storto, riscaldalo e raddrizzalo subito: a freddo non si recupera più.
A3 | Il magnete nella bandierina Ti serve: bandierina, magnete 6 x 3, nastro adesivo, pennarello • Il magnete va nella tasca sulla faccia della bandierina. Non incollarlo ancora: il sensore A3144 risponde a una sola faccia del magnete, e quale sia lo scopri al passo C6. Per ora tienilo a pressione con un velo di nastro. • Segna con un pennarello una faccia del magnete: ti servirà per capire come girarlo.

# Parte B - Elettronica

si prepara e si prova a banco, prima della meccanica

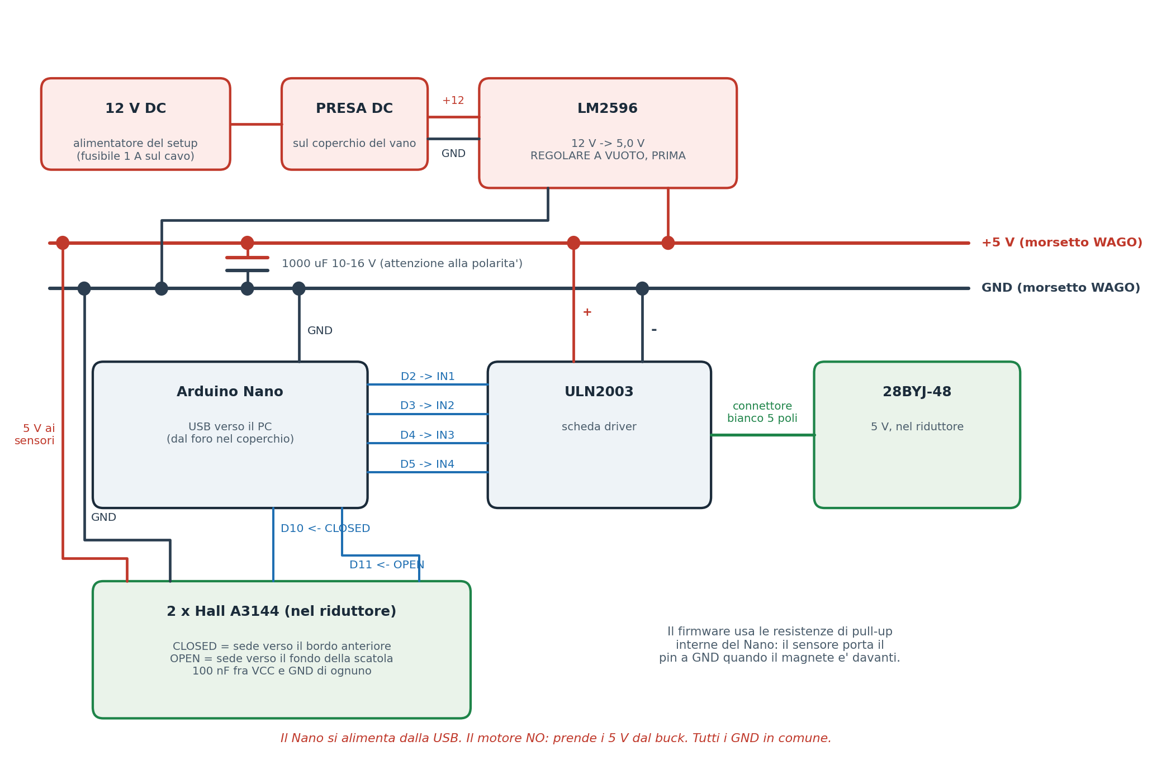
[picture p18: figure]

FIG. B1 - schema elettrico completo
B1 | Regolare il convertitore LM2596, prima di tutto • Collega solo il convertitore ai 12 V, con il fusibile sul cavo. Niente altro a valle. • Con il multimetro sull'uscita gira la vite del trimmer finché leggi 5,00 V (va bene fra 4,95 e 5,10). Il trimmer è multigiro: servono anche venti giri prima di vedere cambiare la tensione. • Stacca i 12 V. Da qui in poi l'uscita del convertitore è il +5 V di tutto il sistema.
B2 | Il coperchio del vano • Monta la presa DC nel foro da 8 mm, con il dado dal lato interno. • Salda due fili di circa 12 cm alla presa (centrale = +12 V, esterno = GND) e portali all'ingresso del convertitore, IN+ e IN-. • Il foro rettangolare è per la spina USB del Nano: resta libero.

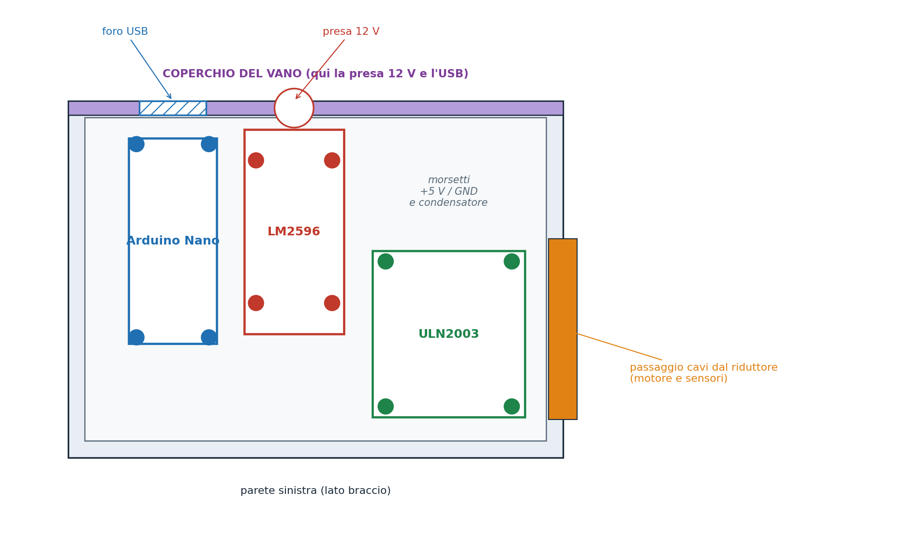
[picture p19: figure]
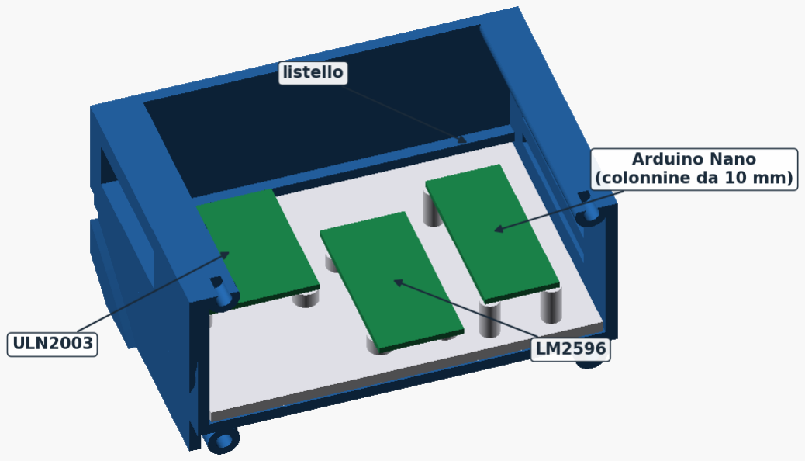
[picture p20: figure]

FIG. B2 - disposizione delle schede sul vassoio (in scala) | FIG. B3 - il vassoio montato dentro il vano
B3 | Montare le schede sul vassoio
- LM2596 sulle quattro colonnine basse vicino al coperchio: ha due soli fori, in diagonale. Usa quelli; le altre due colonnine fanno da appoggio. Il lato IN verso il coperchio, dove arriva la presa.
- ULN2003 sulle quattro colonnine basse dal lato del riduttore, con il connettore bianco del motore rivolto verso il passaggio dei cavi.
- Arduino Nano sulle quattro colonnine alte (10 mm), con la presa USB verso il coperchio. Se i pin del tuo Nano sono già saldati verso il basso, montalo capovolto, componenti verso il vassoio: così i pin puntano in alto e ci innesti i cavetti Dupont. Se i pin sono sciolti, saldali verso l'alto e monta il Nano dritto. In tutti e due i casi la USB resta davanti al foro del coperchio.
- Le misure dei fori delle schede cambiano da un produttore all'altro. Prima di stampare il vassoio misurale con il calibro: se sono diverse correggile nel file SCAD (appendice E). Il vassoio si ristampa in mezz'ora; in alternativa fissa le schede con biadesivo spesso.

### B4 Bus +5 V e GND

- Usa due morsetti WAGO a 5 vie: uno per il +5 V, uno per il GND.
- Al +5 V: OUT+ del convertitore, + della ULN2003, VCC dei sensori, + del condensatore da 1000 uF.
- Al GND: OUT- del convertitore, - della ULN2003, GND dei sensori, - del condensatore, GND del Nano. Senza il GND in comune i segnali dei sensori non hanno riferimento e il motore si comporta in modo casuale.
- Il condensatore ha la striscia bianca sul polo negativo. Montato al contrario si gonfia o scoppia.
- Il Nano si alimenta solo dalla USB: niente fili sul suo pin 5V.

### B5 Nano verso la ULN2003

- Quattro cavetti Dupont: D2 -> IN1, D3 -> IN2, D4 -> IN3, D5 -> IN4.
- Il motore si innesta nel connettore bianco a 5 poli della ULN2003: non c'è niente da cablare. Il connettore entra in un solo verso.

B6 | Preparare i sensori, gia' sulla piastra • Guardando l'A3144 dal lato della faccia marcata (quella con le scritte), con i piedini in basso: a sinistra VCC, al centro GND, a destra l'uscita. • I sensori si cablano sulla piastra, a banco, prima di montarla. Infila ogni A3144 nella sua sede con la faccia marcata verso l'alto: la sede vicino alla lettera incisa C è CLOSED, quella vicino alla O è OPEN. I piedini si stendono nel tratto stretto del canale. • Tutto il cablaggio sta dentro la piastra, sotto il piano su cui passa la bandierina: il canale si allarga a 6 mm, profondo 3,8, e arriva fino al bordo; accanto alla sede c'è l'incavo del condensatore. Niente deve sporgere dal piano. • Accorcia i piedini in modo che entrino di 2-3 mm nel tratto largo. Metti il condensatore da 100 nF sdraiato nel suo incavo e salda le sue gambe su VCC e GND. • Salda ai piedini fili lunghi circa 50 cm (devono arrivare fino al vano), con le tre saldature sfalsate di qualche millimetro e ognuna nella sua guaina. I fili corrono nel canale ed escono di lato dal bordo della piastra. • Riempi canale e incavo con colla a caldo, rasa al piano: isola le saldature e fa da fermacavo. Prima che indurisca controlla che non sporga niente. • Unisci i due VCC e i due GND fuori dalla piastra: al vano arrivano quattro fili, VCC, GND, CLOSED, OPEN. Segna con un pezzo di nastro quale sensore è quale. • Uscita CLOSED -> D10, uscita OPEN -> D11. Non servono resistenze: il firmware usa quelle interne del Nano.
B7 | Caricare il firmware • Apri firmware/GP1_FlipCap_V6/GP1_FlipCap_V6.ino con l'IDE Arduino. • Scheda Arduino Nano, processore ATmega328P. Se il caricamento fallisce, scegli ATmega328P (Old Bootloader): è il caso di quasi tutti i cloni. • In alternativa carica il file già compilato firmware/build/GP1_FlipCap_V6.ino.hex con avrdude (istruzioni nel README della cartella). • Non cambiare niente al primo caricamento.
B8 | Prova a banco • Collega i 12 V, il motore alla ULN2003 e il Nano al PC. Motore libero, non montato. • Apri il monitor seriale a 9600 baud con terminatore Nuova riga (LF) e prova i comandi della tabella. • Con >O000 l'albero del motore deve girare in modo regolare. Nessun sensore scatta, quindi dopo circa un minuto il motore si ferma da solo e lo stato diventa 3: è giusto. • Durante il movimento avvicina il magnete al sensore OPEN: il motore si deve fermare subito e lo stato diventa 2. Se non succede, gira il magnete dall'altra faccia. Stessa prova con >C000 e il sensore CLOSED (stato 1). • Se il motore vibra senza girare, controlla l'ordine D2-D5 verso IN1-IN4.
Mandi | Risposta | Significato
>P000 | *P98000 | ping: risponde il product ID 98
>V000 | *V98160 | versione del firmware
>S000 | *S98xyz | stato: x motore, y luce (sempre 0), z tappo
>O000 | *O98000 | apri
>C000 | *C98000 | chiudi
Cifra | Valori
x (motore) | 0 = fermo, 1 = in movimento
z (tappo) | 0 = in mezzo, 1 = chiuso, 2 = aperto, 3 = fermo per errore (sensore non trovato)

# Parte C - Il riduttore

dall'housing vuoto al meccanismo tarato e chiuso

Prima di cominciare guarda l'esploso. Ogni pezzo entra lungo il suo asse, nell'ordine in cui lo vedi, dalla parete sinistra verso il coperchio. Le viti disegnate a sinistra e sotto la scatola entrano da fuori: la vite M5 del composto, le due M3 x 16 della piastra sensori e le due M3 x 8 della staffa. Anche l'albero entra da fuori, attraverso il cuscinetto della parete.

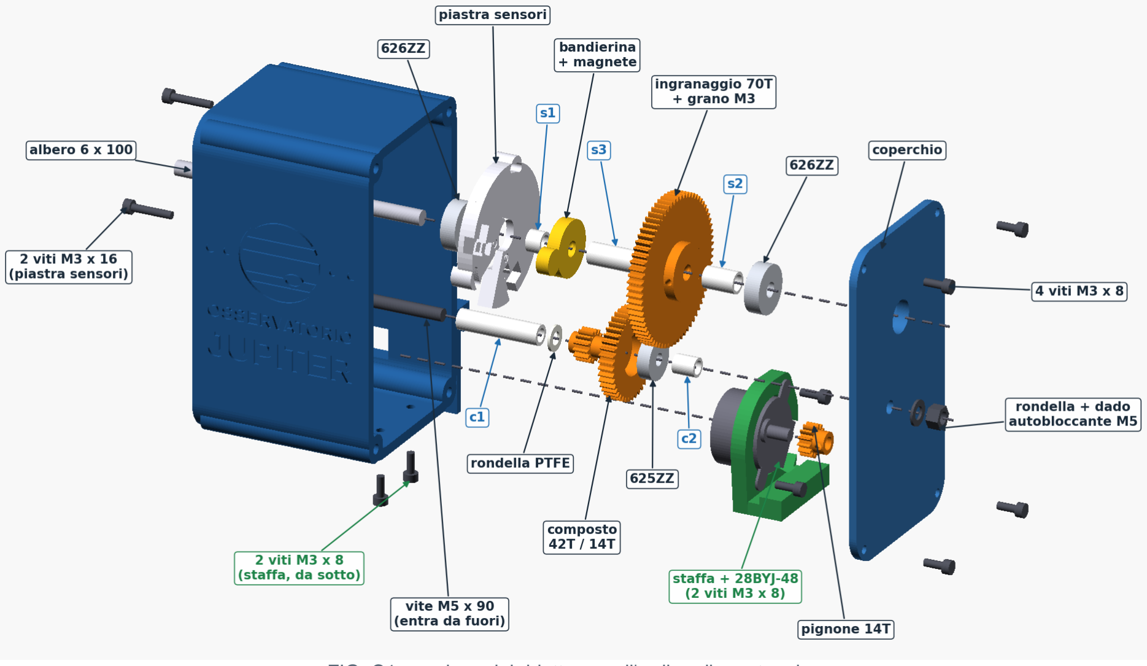
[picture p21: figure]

FIG. C1 - esploso del riduttore, nell'ordine di montaggio

## Come è tenuto ogni pezzo

Pezzo | Come è tenuto | Viteria | Passo
cuscinetti 626ZZ | a pressione nella parete sinistra e nel coperchio, inseriti dall'interno; battono su un labbro esterno | - C1
piastra sensori | avvitata alla parete sinistra su due asole, che la lasciano ruotare di 7 gradi per parte per la taratura | 2 M3 x 16, 2 rondelle, 2 dadi | C2
albero 6 x 100 | gira nei due 626ZZ. Il pacco s1 - bandierina -s3 - 70T - s2 sta fra i due cuscinetti: chiuso il coperchio, l'albero non si sfila da nessuna parte, senza anelli elastici | - C3, C9
bandierina, ingranaggio 70T | un grano ciascuno, stretto su un piano limato sull'albero | 2 grani M3 x 5 | C3
magnete | nella tasca della bandierina, incollato dopo la prova dei sensori | cianoacrilica | C6
staffa motore | sul fondo della scatola, avvitata da sotto negli inserti del suo piede | 2 M3 x 8, 2 inserti | A2, C4
motore 28BYJ-48 | orecchie avvitate alla staffa; i fori larghi delle orecchie servono a registrare l'ingranamento | 2 M3 x 8 (si filettano nella plastica) | C4, C7
composto 42T / 14T | gira su un 625ZZ e sulla vite M5, che fa da perno fra parete e coperchio; c1, c2 e la rondella PTFE lo tengono in posizione | M5 x 90, 2 rondelle, dado autobloccante | C5, C9
pignone 14T | grano nel mozzo, stretto su uno dei due piani dell'albero del motore | 1 grano M3 x 5 | C7
coperchio del riduttore | negli inserti dei quattro angoli | 4 M3 x 8, 4 inserti | A2, C9
braccio | mozzo a morsetto sull'albero, fuori dalla scatola | M3 x 25 e dado | D3
vassoio e schede | vassoio fra il listello della parete e quello del coperchio, senza viti; schede sulle colonnine | viti autofilettanti | B3, D1
coperchio del vano | negli inserti del vano | 4 M3 x 8 svasate, 4 inserti | A2, D1
scatola sul tubo | due selle rivestite di EVA, due cinghie a strappo | 2 cinghie da 25 mm | D2
tappo | stretto fra la piastra del braccio e la contropiastra | 4 M4 x 16, rondelle larghe, dadi | D4
appoggi del tappo | una cinghia a strappo ciascuno, attorno al tubo | 2 cinghie | D5

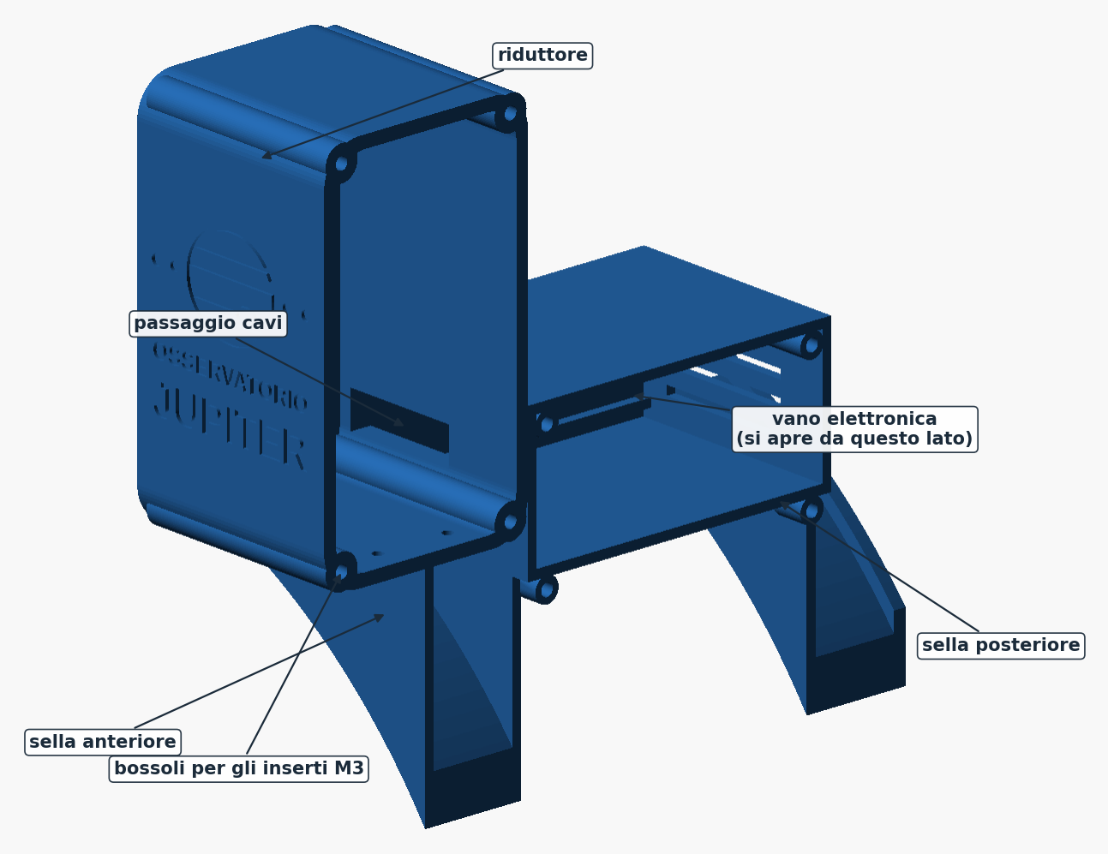
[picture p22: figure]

FIG. C2 - l'housing visto dal lato aperto
C1 Cuscinetti 626ZZ Ti serve: 2 cuscinetti 626ZZ, la scatola, il coperchio del riduttore • Spingi un 626ZZ nella sede della parete sinistra dall'interno della scatola, finché batte sul labbro esterno. • Spingi il secondo 626ZZ nella sede del coperchio, anche questo dal lato interno. • Se entrano troppo morbidi, una goccia di frenafiletti medio sul diametro esterno.

C2 Piastra dei sensori - va montata prima dell'albero Ti serve: piastra sensori, i due A3144 cablati al passo B6, 2 viti M3 x 16 con 2 rondelle e 2 dadi, colla a caldo • I due A3144 sono già nelle loro sedi e cablati (passo B6), con la faccia marcata verso l'interno della scatola, dove passerà il magnete. I fili escono dal canale sul bordo della piastra: niente fili sopra il piano, sotto la piastra o vicino al foro centrale. • La sede rivolta verso il bordo anteriore della scatola (lato tappo) è quella del sensore CLOSED; la sede rivolta verso il fondo della scatola (lato tubo) è quella del sensore OPEN. Guarda la figura C3. • Fissa la piastra con due viti M3 x 16 infilate dall'esterno della parete sinistra, rondella e dado dentro. Stringi appena: le asole servono alla taratura del passo C6. • Porta i quattro fili lungo la parete fino al passaggio in basso verso il vano, e fermali con una goccia di colla a caldo lontano dagli ingranaggi.

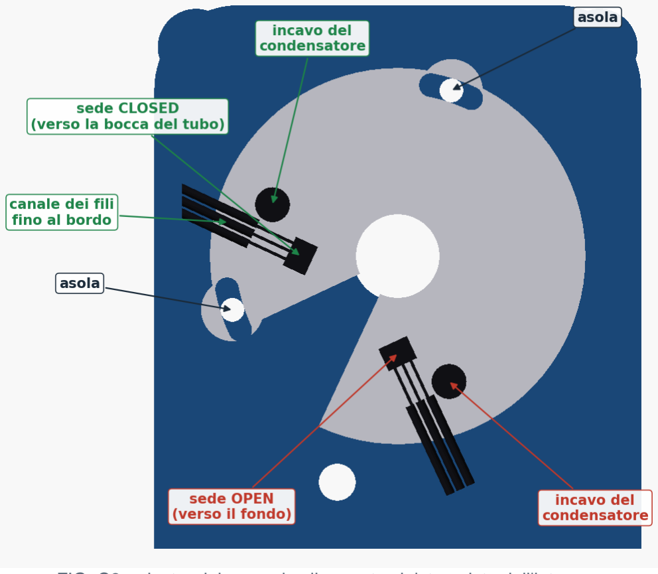
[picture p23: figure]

FIG. C3 - piastra dei sensori sulla parete sinistra, vista dall'interno

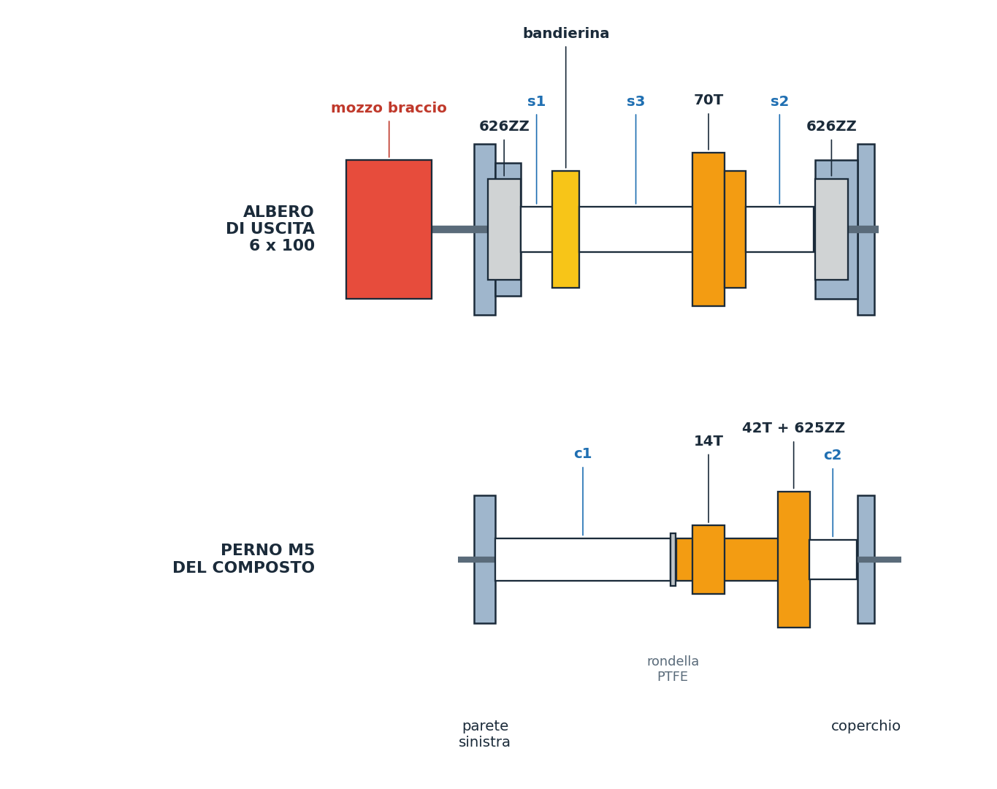
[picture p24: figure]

FIG. C4 - l'ordine dei pezzi sui due assi

C3 Albero di uscita, distanziali, bandierina, ingranaggio 70T Ti serve: albero Ø6 x 100, distanziali s1, s3 e s2, bandierina con il magnete, ingranaggio 70T, 2 grani M3 x 5, lima piatta, brugola da 1,5 mm • Con una lima fai due piccoli piani sull'albero dove appoggeranno i grani: a 41 mm e a 73 mm da un'estremità. Quell'estremità è il lato del braccio. • Infila l'albero dall'esterno attraverso il 626ZZ della parete, lato braccio verso l'esterno, finché ne sporgono 24 mm fuori dalla parete. • Dall'interno infila in quest'ordine: s1 (il corto da 6 mm), la bandierina con il magnete verso i sensori, s3 (21 mm), l'ingranaggio 70T con il mozzo verso il coperchio, s2 (13 mm). • Spingi tutto verso la parete: s1 appoggia sul cuscinetto, e bandierina e ingranaggio si trovano da soli al posto giusto. Stringi i due grani sui piani dell'albero. • Gira l'albero a mano: la bandierina non deve toccare la piastra dei sensori in nessun punto. • Con l'albero di prova (appendice G): non c'è niente da limare, il piano corre per tutta la lunghezza. Giralo in modo che i due grani appoggino sul piano e stringili senza forzare.

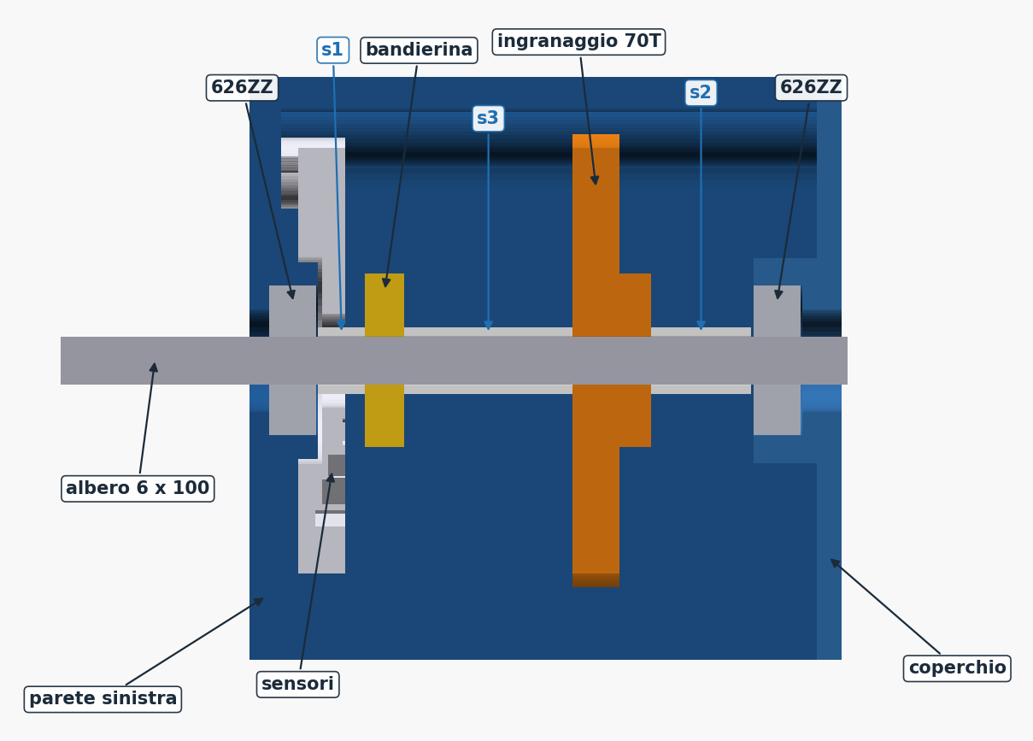
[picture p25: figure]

FIG. C5 - albero con distanziali, bandierina e ingranaggio di uscita

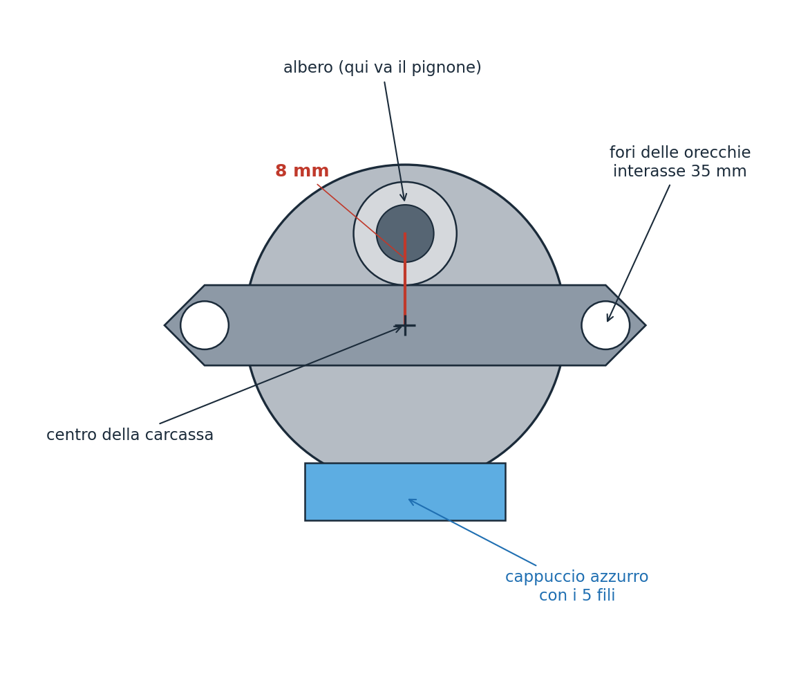
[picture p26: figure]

FIG. C6 - il 28BYJ-48 visto dal lato dell'albero

C4 Motore e staffa Ti serve: staffa motore, 28BYJ-48, 4 viti M3 x 8 (2 per le orecchie, 2 da sotto il fondo), brugola da 2,5 mm • Il 28BYJ-48 ha l'albero fuori centro di 8 mm (figura C6): la staffa ha già il foro nella posizione giusta, ma devi infilare il motore con il cappuccio azzurro dei fili verso l'intaglio della staffa. • Il corpo del motore passa nel foro della staffa e le orecchie appoggiano sulla faccia rivolta verso il coperchio. Avvitale con due M3 x 8: le viti si filettano da sole nella plastica. Stringi appena. • Porta il cavo del motore verso il passaggio per il vano. • Metti la staffa sul fondo del riduttore e avvitala da sotto la scatola con due M3 x 8 negli inserti del piede. • Il pignone non si monta ancora.

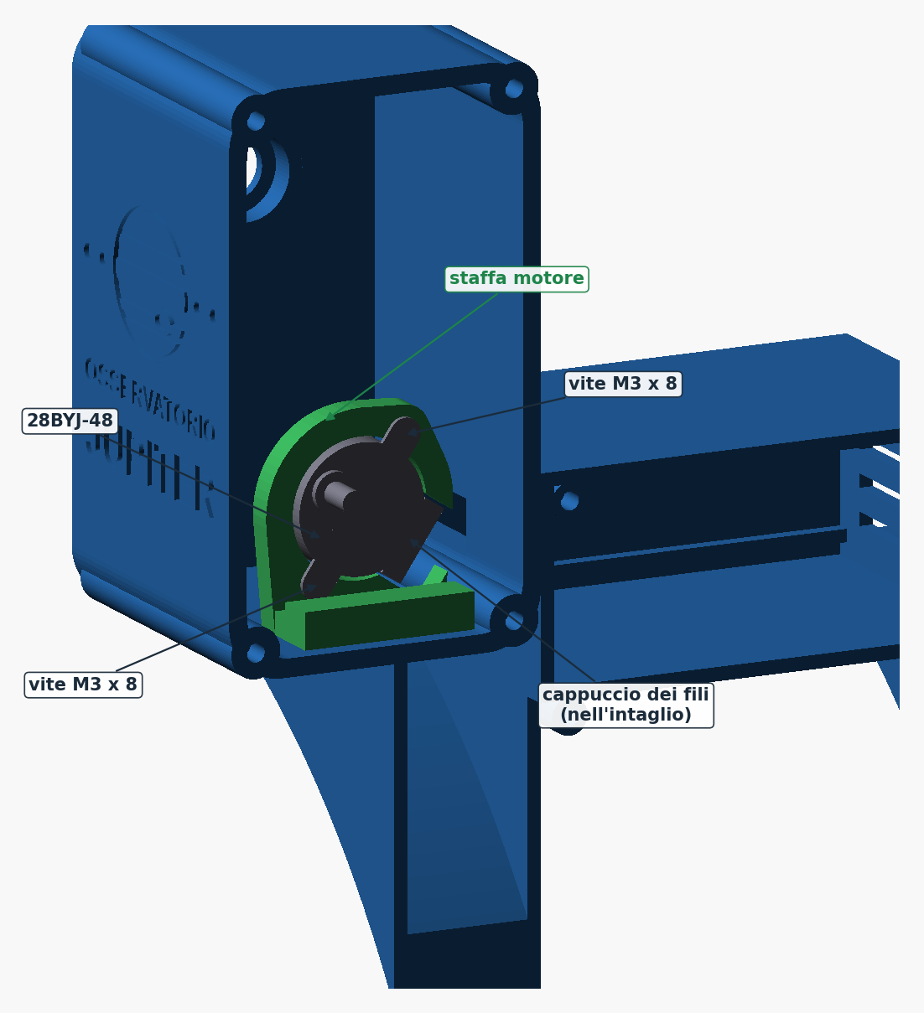
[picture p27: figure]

FIG. C7 - staffa e motore montati sul fondo del riduttore

C5 Ingranaggio composto Ti serve: ingranaggio composto, cuscinetto 625ZZ, vite M5 x 90 con una rondella, distanziali c1 e c2, rondella in PTFE • Pianta il 625ZZ nella sede del lato 42T del composto. • Infila la vite M5 x 90 dall'esterno della parete sinistra, con una rondella sotto la testa. Usala a testa cilindrica o esagonale, alta al massimo 5 mm: il braccio le passa accanto a 2 mm. • Dall'interno infila sulla vite, in quest'ordine: il distanziale c1 (il lungo), la rondella in PTFE, il composto (lato 14T verso la parete), il distanziale c2. Facendolo scorrere, ruotalo un poco finché i denti entrano fra quelli del 70T. • Il composto deve girare libero e avere un filo di gioco assiale. La vite arriverà al coperchio al passo C9. • Con il perno di prova (appendice G): infilalo come la vite, senza rondella: la testa fa da rondella.

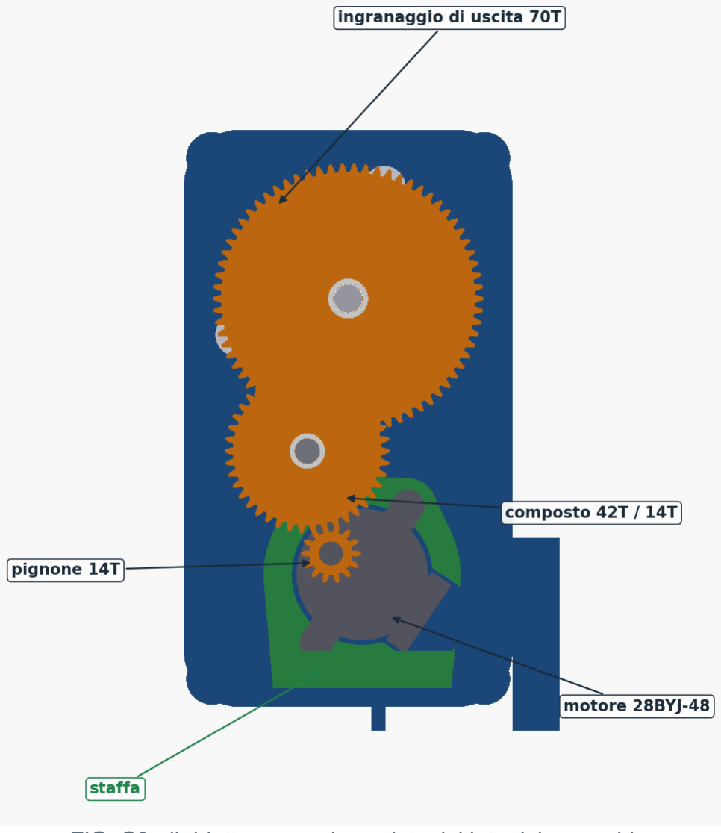
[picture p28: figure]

FIG. C8 - il riduttore completo, visto dal lato del coperchio
C6 | Taratura dei sensori, a mano
| Ti serve: l'elettronica della parte B collegata al PC, cianoacrilica • Collega l'elettronica preparata nella parte B e apri il monitor seriale. Il pignone non c'è: l'albero di uscita gira liberamente a mano. • Ruota l'albero finché il magnete è davanti al sensore CLOSED e manda >S000: l'ultima cifra deve essere 1. • Se resta 0, prima di tutto gira il magnete nella sua tasca: l'A3144 è unipolare e risponde a una sola faccia. Quando funziona, incolla il magnete con una goccia di cianoacrilica. • Ruota l'albero di 270 gradi nel verso di apertura (il magnete si porta davanti al sensore OPEN): l'ultima cifra deve diventare 2. • Per regolare il punto di scatto allenta le due viti della piastra e ruotala nelle asole, poi stringi. Le asole muovono insieme i due sensori, che restano sempre a 270 gradi l'uno dall'altro.

C7 | Pignone e ingranamento del motore Ti serve: il pignone 14T, un grano M3 x 5, brugole da 1,5 e 2,5 mm • Infila il pignone sull'albero del motore fino al collarino, con il mozzo verso il coperchio: i denti devono allinearsi con quelli del 42T. Ruota il composto di un pelo per farli entrare. • Gira il pignone finché il grano guarda uno dei due piani dell'albero e stringilo con la brugola da 1,5 mm. • Allenta le due viti delle orecchie. I fori delle orecchie sono più larghi delle viti: spingi il motore verso il composto finché il pignone ingrana senza forzare, poi tornalo indietro di un soffio, così resta un minimo gioco percepibile. Stringi. • Troppo stretto: il motore fatica e salta dei passi. Troppo lasco: i denti scavalcano sotto sforzo. • Da adesso il braccio non si gira più a mano.
C8 | Verso di rotazione e prova a vuoto • Manda >C000: il meccanismo si porta sul sensore CLOSED e si ferma (stato 1). • Manda >O000: la bandierina deve muoversi verso il sensore OPEN. Se va nel verso sbagliato, fermala con >C000, metti MOTOR_REVERSED = true nel firmware e ricaricalo. • La corsa completa deve durare circa 55 secondi e finire con lo stato 2. Molto di più, o uno stato 3, significa passi persi o sensore non raggiunto.
C9 | Chiudere il riduttore Ti serve: coperchio del riduttore con il suo 626ZZ, 4 viti M3 x 8, una rondella M5, il dado autobloccante M5, chiave da 8 mm • Ultimo controllo: nessun filo vicino agli ingranaggi, tutti fermati con colla a caldo o una fascetta. • Appoggia il coperchio: l'albero di uscita entra nel suo 626ZZ e la vite M5 nel foro. Avvitalo con quattro M3 x 8. • Sulla vite M5, fuori dal coperchio: rondella e dado autobloccante, portato a contatto senza stringere. Il composto deve continuare a girare libero. • La vite deve uscire dal dado di qualche filetto, altrimenti l'anello di nylon non la blocca: con la M5 x 90 ne escono circa 8 mm. Se vuoi accorciarla, lasciane fuori almeno 3. • Con il perno di prova: al posto di rondella e dado infila la ghiera fuori dal coperchio, fino a sfiorarlo.

# Parte D - Sul telescopio

fissaggio, braccio, tappo, appoggi, collaudo

D1 | Chiudere il vano elettronica Ti serve: vassoio con le schede (passo B3), coperchio del vano, 4 viti M3 x 8 a testa svasata, brugola da 2 mm • Infila il vassoio nel vano di taglio: il bordo interno va sotto il listello della parete sinistra. • Collega il cavo del motore alla ULN2003 e i quattro fili dei sensori, che arrivano dal passaggio. • Chiudi con il coperchio del vano: il suo listello interno tiene fermo l'altro bordo del vassoio. Quattro viti M3 x 8 svasate.
D2 | Montare la scatola sul tubo Ti serve: EVA adesiva da 2 mm, 2 cinghie a strappo da 25 mm • Incolla l'EVA da 2 mm sulla faccia interna delle due selle. • Posiziona la scatola con il suo bordo anteriore 10 mm oltre la bocca del tubo: l'albero del braccio cade così 25 mm dietro la bocca, come nel progetto. Puoi ruotare tutto attorno al tubo per evitare cercatori o focheggiatori: basta che il tappo parcheggiato trovi il tubo sotto di sé e che gli appoggi possano stare sulla parte alta del tubo. • Passa una cinghia attorno al tubo sopra ognuna delle due selle, fra le due costole, e stringi bene. • Aggiungi circa 700 g in testa al tubo: ribilancia la montatura.

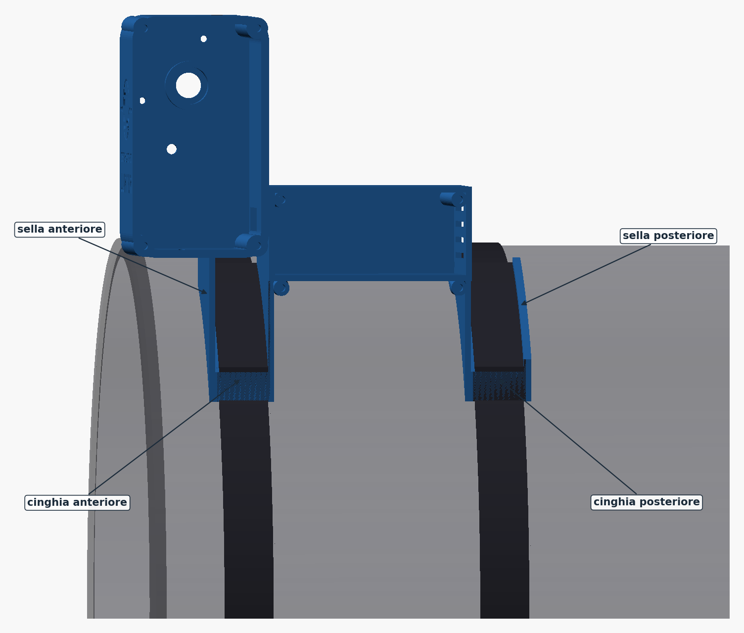
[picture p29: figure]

FIG. D1 - le due cinghie passano sopra le selle, fra le costole

D3 Braccio Ti serve: braccio, vite M3 x 25 con il dado, brugola da 2,5 mm, chiave da 5,5 mm • Manda >C000: l'albero si porta in posizione CLOSED. • Infila il mozzo del braccio sull'albero, a filo dell'estremità. Il mozzo è a morsetto: entra libero. • Non spostarlo verso la scatola: fra mozzo e parete restano 8 mm, e la testa della vite M5 con la sua rondella ne occupa 6. • Orienta il braccio in modo che la sua piastra sia davanti alla bocca del tubo e parallela alla bocca, e stringi la vite M3 x 25 con il dado nella sua sede. Stringi deciso: è questo morsetto che trasmette tutta la coppia. • Con l'albero di prova: stringi il morsetto con giudizio, la plastica cede. Per provare la corsa con il tappo monta la vite M5 vera al posto del perno di prova (appendice G).

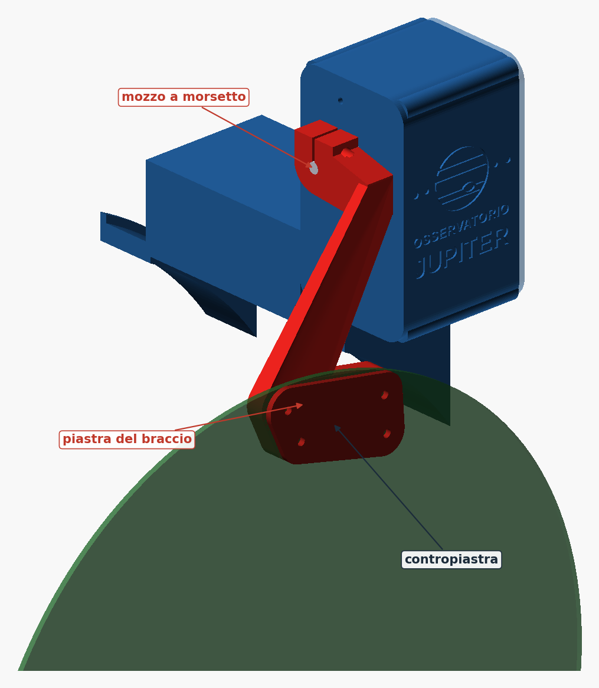
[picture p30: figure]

FIG. D2 - braccio e contropiastra
D4 Tappo Ti serve: lastra del tappo, contropiastra, 4 viti M4 x 16, 4 rondelle larghe, 4 dadi M4, trapano con punta da 4,5 mm, cutter, spago e puntina • Traccia il cerchio con uno spago e una puntina e taglia il disco con il cutter (374 mm con le misure di default). Canali del polipropilene orientati come spiegato al capitolo 0.7. • Appoggia il disco sulla piastra del braccio, centrato sulla bocca del tubo, e usa la contropiastra come dima per i quattro fori da 4,5 mm. • I dadi M4 vanno nelle sedi esagonali sotto la piastra del braccio. Viti M4 x 16 dal lato cielo con rondelle larghe, attraverso la contropiastra e il disco. Stringi senza schiacciare il polipropilene. • Facoltativo, per i dark: un anello di gomma crepla sul lato interno del tappo, alto quanto basta a sfiorare l'anello del tubo. Pesa: rileggi il margine al capitolo 0.7.

D5 Appoggi del tappo Ti serve: 2 appoggi del tappo, 2 cinghie a strappo, EVA adesiva da 2 mm • Incolla 2 mm di EVA sulla faccia superiore di ogni appoggio e sotto, dove tocca il tubo. • Fissali sulla generatrice più alta del tubo, dalla parte della scatola, con una cinghia ciascuno: il primo a 215 mm dalla bocca del tubo, il secondo a 380 mm. • Manda >O000 e guarda l'ultimo tratto della corsa: il tappo si deve posare sui due appoggi proprio quando il motore si ferma. Se si ferma prima, sollevato di qualche millimetro, aggiungi EVA; se si posa e il motore continua a girare, toglila.

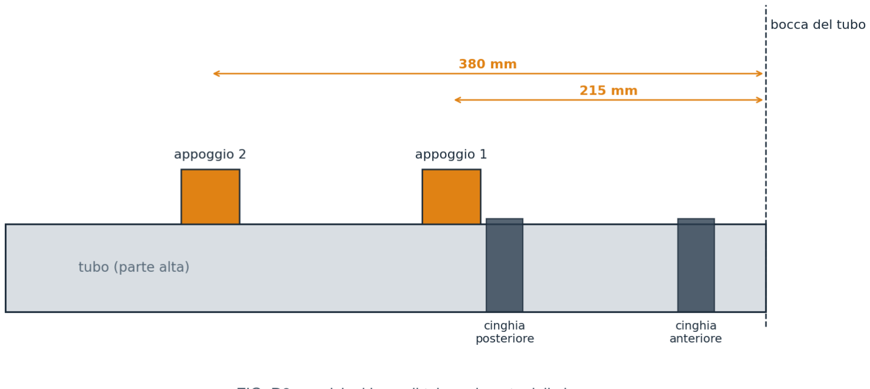
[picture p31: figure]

FIG. D3 - posizioni lungo il tubo, misurate dalla bocca
D6 Collaudo • Apri e chiudi almeno dieci volte di seguito: lo stato finale deve essere sempre 1 o 2, mai 3. • Ripeti con il telescopio nelle posizioni in cui lo parcheggi davvero. • Controlla che il tappo chiuso copra tutta la bocca e che, aperto, stia fermo sugli appoggi anche dando un colpetto al tubo.

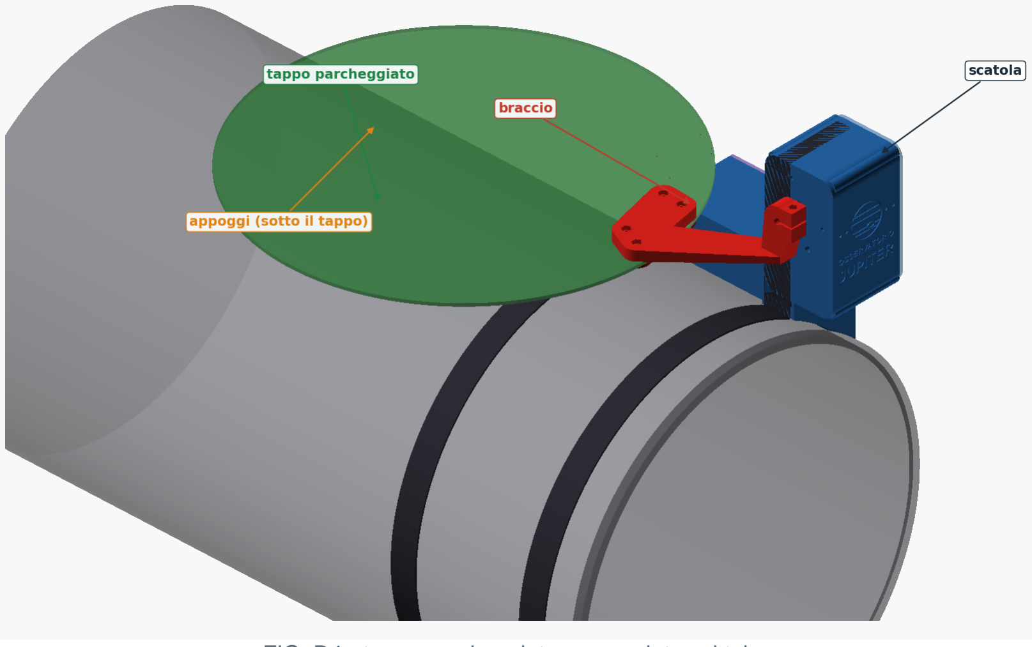
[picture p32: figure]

FIG. D4 - tappo parcheggiato, appoggiato sul tubo

D7 Ekos / INDI • Driver Flip Flat (indi_flipflat), porta seriale del Nano, 9600 baud. • Park = chiudi, Unpark = apri. • La corsa dura circa 55 secondi, più dei 30 dopo i quali il driver INDI ripete il comando e scrive nel log Parking cap timed out. Retrying. È normale: il firmware riconosce il comando ripetuto e lo ignora, e la corsa finisce regolarmente. • Usa il tappo a telescopio fermo: aprilo prima di sparcheggiare e chiudilo dopo aver parcheggiato.

# Appendici

## A. Comandi seriali (protocollo Alnitak)

9600 baud, 8N1, ogni comando termina con un a capo (LF). Il firmware emula l'Alnitak Remote Dust Cover, product ID 98.

Comando | Risposta | Effetto
>P000 | *P98000 | ping
>O000 | *O98000 | apri il tappo
>C000 | *C98000 | chiudi il tappo
>S000 | *S98xyz | stato: x motore, y luce, z tappo
>V000 | *V98160 | versione del firmware
>J000 | *J98000 | luminosità (non usata)
>B, >L, >D | *B98000 ... | comandi del pannello luminoso: rispondono ma non fanno niente

## B. Coppia, velocità e peso del tappo

Coppia disponibile stimata: circa 30 mN·m del 28BYJ-48 a 12 giri al minuto, moltiplicati per la riduzione 15:1 e per un rendimento di 0,72 sui due stadi: circa 0,32 N·m sull'albero di uscita. Il valore reale cambia da motore a motore. Coppia richiesta: il caso peggiore è il braccio orizzontale, con il centro del tappo a 267 mm dall'albero. Il braccio (circa 57 g) pesa come se stesse a 67 mm, contropiastra e viti (circa 27 g) a 108 mm.
Se il tappo non si alza e hai già il materiale più leggero, rallenta il motore: il 28BYJ ha più coppia a bassa velocità. Nel firmware porta STEP_INTERVAL_US da 2400 a 3000 e MOVE_TIMEOUT_MS da 70000 a 90000 (la corsa passa a circa 70 secondi). Se non basta ancora serve un motore più forte.

## C. Diagnostica

Sintomo | Causa probabile | Cosa fare
Il motore vibra ma non gira | ordine delle fasi | controlla D2-D5 verso IN1-IN4
Gira nel verso sbagliato | - | MOTOR_REVERSED = true nel firmware
Lo stato resta sempre 0 | nessun sensore scatta | gira il magnete; controlla VCC, GND e il GND in comune col Nano
Stato 3 a fine corsa | il sensore di arrivo non scatta | gira il magnete o registra la piastra (passo C6)
Stato 3 dopo pochi secondi | il motore stalla | controlla l'ingranamento (C7); tappo più leggero; motore più lento (appendice B)
Il tappo si ferma sopra gli appoggi | EVA troppo sottile | aggiungi EVA sugli appoggi
A fine apertura il motore insiste | EVA troppo spessa | togli EVA
Rumore ciclico dagli ingranaggi | pignone troppo spinto contro il 42T | rifai il passo C7
Il Nano si resetta quando parte il motore | motore alimentato dal Nano | il motore va sul +5 V del convertitore (B4)
La scatola ruota attorno al tubo | cinghie lente o EVA mancante | stringi le cinghie; l'EVA sotto le selle è necessaria

## D. Limiti verificati

Le luci qui sotto sono misurate sulle mesh dei pezzi, montate in posizione, lungo tutta la corsa (passi di 3 gradi). Lo script è docs/verifica_collisioni.py; il risultato completo è in docs/VERIFICA_COLLISIONI.txt.

Grandezza | Luce minima
Bandierina - piastra dei sensori (traferro) | 2,50 mm
Braccio e contropiastra - appoggi del tappo | 43,90 mm
Braccio - scatola, su tutta la corsa | 8,00 mm
Braccio - tubo | 36,50 mm
Disco del tappo - appoggi, prima dell'arrivo | 10,83 mm
Disco del tappo - coperchio del vano | 14,93 mm
Disco del tappo - coperchio del riduttore | 51,26 mm
Disco del tappo - scatola | 7,50 mm
Disco del tappo - tubo (esclusi gli appoggi) | 39,50 mm
Tappo parcheggiato - coperchio del vano | 7,5 mm

Extracorsa. Se il sensore OPEN non scatta, oltre i 270 gradi il tappo è già sugli appoggi: il motore si ferma contro di loro, cosa che il 28BYJ sopporta, e il firmware lo spegne al più tardi dopo MAX_MOVE_STEPS = 24.100 passi (circa 284 gradi) o 70 secondi, segnalando lo stato 3. In chiusura, oltre lo zero il tappo va in appoggio sull'anello del tubo.

## E. Rigenerare i pezzi con misure diverse

Serve OpenSCAD (la libreria MCAD è già inclusa). Tutti i parametri sono in testa a gp1_flipcap_V6.scad, commentati. Aprendo il file e premendo F5 si vede l'assieme; cap_angle muove il tappo.

Cosa cambi | Parametro | Pezzi da rigenerare
diametro del tubo | ota_d | housing, cap_rest
spessore del tappo | cap_thickness | mono_arm, cap_rest
diametro del tappo | cap_d | nessuno: è solo la misura a cui tagli il disco
fori delle schede | nano_holes, uln_holes, buck_holes | bay_tray
distanza degli appoggi | rest_z | nessuno
logo sulla scatola | logo=false | housing

Da riga di comando, un pezzo alla volta:

openscad -o stl/housing.stl -D 'part="housing"' -D ota_d=355 gp1_flipcap_V6.scad
Dopo ogni modifica rilancia la verifica, che rifa' da sola tutti i controlli di questo manuale sulle mesh nuove (servono Python con numpy e scipy):

python docs/verifica_collisioni.py
Impiega una ventina di minuti: esporta tutti i pezzi da OpenSCAD e prova la corsa ogni 3 gradi.

## F. Se hai già stampato pezzi di versioni precedenti

Il composto e il pignone hanno la stessa geometria dalla V4.1 in poi e si riusano; l'ingranaggio di uscita si riusa dopo averlo forato (qui sotto). La bandierina della V4.1 ha la tasca del magnete chiusa dentro il pezzo e va ristampata. Tutto il resto è nuovo e va stampato.

Ingranaggio | Denti | Diametro esterno
uscita | 70 | 57,6 mm
composto | 42 + 14 | 35,2 mm e 12,8 mm
pignone del motore | 14 | 12,8 mm

Gli ingranaggi della prima versione non vanno bene. Prima della V4.1 il treno era diverso (pignoni da 12 denti, uscita più piccola) e non ingrana con queste distanze fra gli assi. Misura i tuoi: se non corrispondono alla tabella qui sopra, ristampali dalla cartella stl/. Non scalarli nello slicer: cambia la misura dei denti e non ingranano più.

Attenzione all'ingranaggio di uscita delle V4.x. Nelle versioni precedenti il foro del grano cadeva sulla faccia dell'ingranaggio invece che nel mozzo, e il grano non poteva stringere l'albero. Se riusi quel pezzo, fora il mozzo a metà della sua parte sporgente, in radiale, con una punta da 2,5 mm, e usa una vite M3 che si filetta da sola. Il file output_gear.stl della V6 ha già il foro giusto.

## G. Assi di prova in plastica (facoltativi)

test_shaft e test_pin sono l'albero di uscita e il perno del composto in versione stampata. Servono a montare e provare il riduttore prima di tagliare l'albero d'acciaio e di comprare la vite M5. Il perno di prova ha una ghiera elastica che si infila a pressione e prende il posto del dado. I diametri sono un decimo sotto il nominale (5,9 e 4,9 mm): entrano nei cuscinetti senza forzare. Se ballano, una passata di nastro adesivo; se sono stretti, carta vetrata fine. Il piano lungo tutto l'asse li tiene sul piatto e fa da sede ai grani.

Impostazione (Bambu Studio) | Valore | Perché
profilo | 0.12mm High Quality | layer sottili e pareti esterne lente: il tondo viene preciso
pareti | 8 | il pezzo è tutto pareti che corrono lungo l'asse
riempimento | 100%, rettilineo | pieno; il riempimento a griglia non accetta il 100%
altezza Z precisa | sì | il diametro viene giusto anche in verticale
supporti | no | il piano lungo l'asse appoggia sul piatto
orientamento | sdraiati, come nel file | le linee lungo l'asse resistono meglio a flessione e torsione
materiale | PLA o PLA+ | fra i filamenti comuni è il più rigido: il PETG si flette di più

Sull'A1 i due assi insieme richiedono circa 17 minuti e 5,5 g di filamento.

Prova | Con gli assi di plastica
montaggio, ordine dei passi, ingranamento girando a mano | sì
taratura dei sensori (passo C6) | sì
corsa del motore senza tappo (passo C8) | sì
corsa con il tappo montato | solo con la vite M5 vera al posto del perno di prova
uso sul telescopio | no: albero d'acciaio e vite M5

Perché non sotto carico. Con il tappo montato i denti spingono sul composto con 8-12 N. Il perno di prova, lungo 68 mm fra parete e coperchio, si flette di 0,5-1 mm: più di metà dell'altezza utile dei denti, e il 14T può saltare sul 70T. L'albero di prova regge, ma fra ingranaggio e braccio si torce di circa 5 gradi, e se il tappo resta chiuso per giorni la torsione diventa permanente. I grani affondano nella plastica: stringili senza forzare. Sopra i 55-60 gradi il PLA si ammorbidisce: niente prove al sole.

Per passare all'acciaio: sfila la ghiera, apri il coperchio, allenta i due grani e il morsetto e togli il braccio. Spingi dentro l'albero d'acciaio dal lato del braccio, con i piani già limati (passo C3): quello di plastica esce dall'altra parte, e distanziali, bandierina e ingranaggio restano infilati. Allo stesso modo spingi dentro la vite M5 dal lato della testa del perno: il perno esce e il composto resta al suo posto (passo C5). Richiudi (C9) e ricontrolla la taratura dei sensori (C6) e la posizione del braccio (D3).

Documento generato automaticamente: docs/genera_figure_manuale.py crea le figure dal modello, docs/genera_manuale_pdf.py impagina, docs/contenuto_manuale.py contiene il testo.

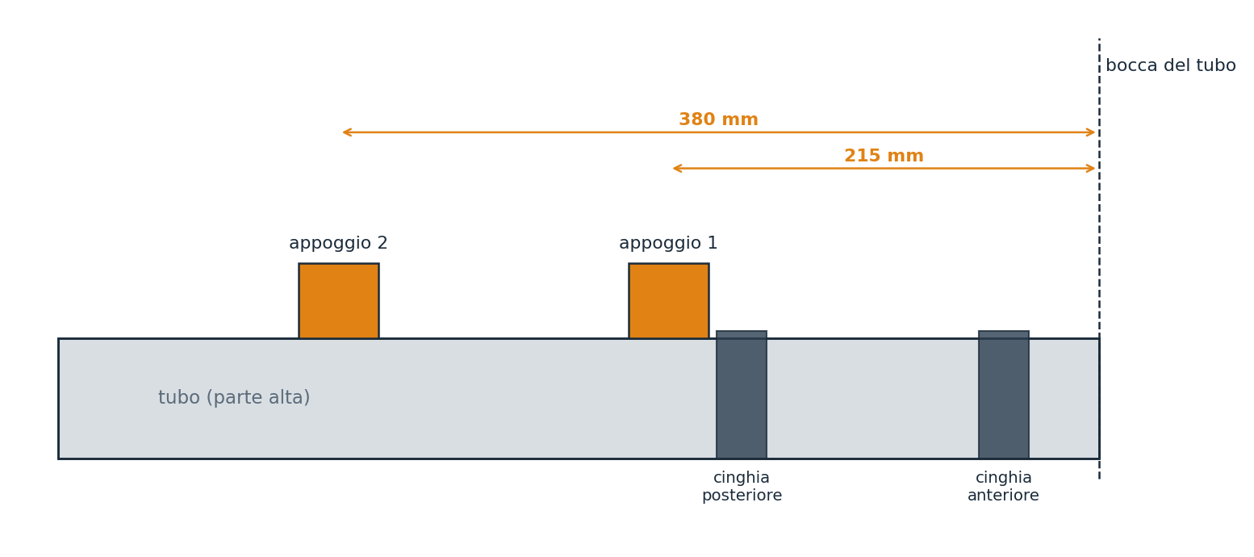
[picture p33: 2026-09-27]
docs/manuale/F15_appoggi.png

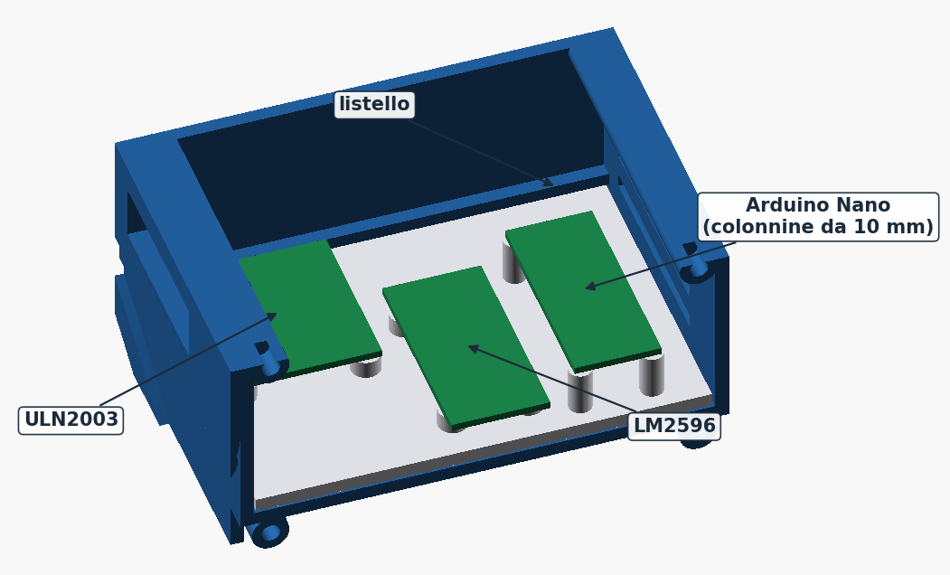
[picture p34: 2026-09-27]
docs/manuale/F11_vano.png

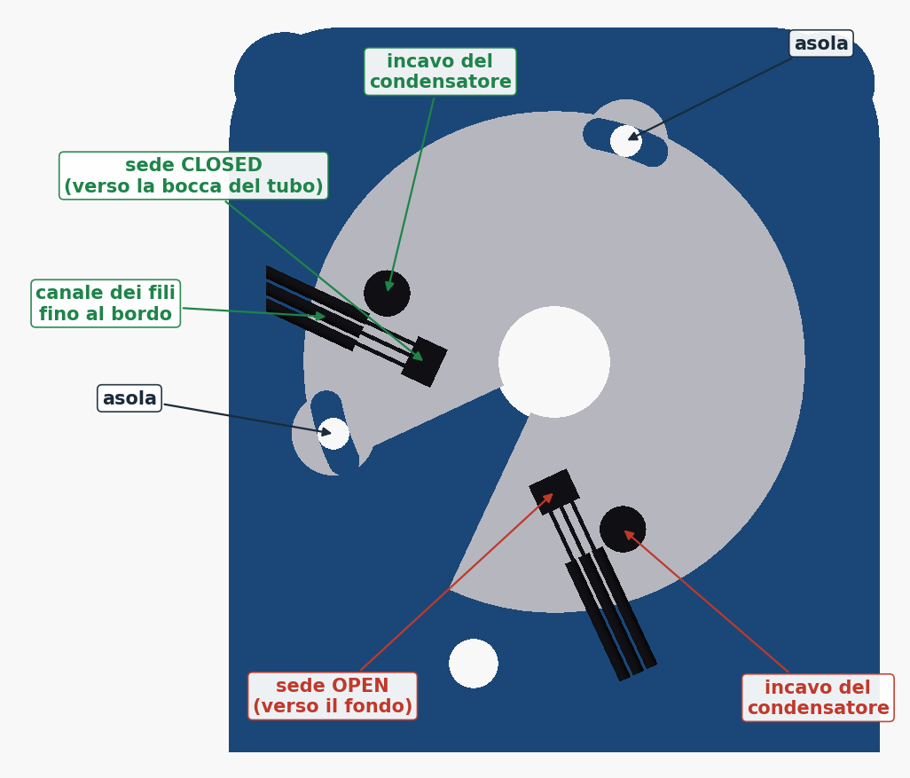
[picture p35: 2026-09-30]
docs/manuale/F07_piastra_sensori.png

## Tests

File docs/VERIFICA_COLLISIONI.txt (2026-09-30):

GP1 FlipCap V6 - VERIFICA GEOMETRICA AUTOMATICA
======================================================================
cerniera Y=264.0 Z=-25.0  braccio X=68.0  tappo D=374 sp.3.0  tubo D=362

1) PEZZI DA STAMPARE (stl/): ogni file deve essere un solido unico
   OK bay_lid            corpi=1   104.0 x   56.0 x    6.0 mm    17.1 cm3  base Z=0.00
   OK bay_tray           corpi=1    68.0 x   97.0 x   13.0 mm    21.4 cm3  base Z=0.00
   OK cap_backplate      corpi=1    83.5 x   53.0 x    3.0 mm     9.2 cm3  base Z=0.00
   OK cap_rest           corpi=1    60.0 x   40.0 x   38.8 mm    66.1 cm3  base Z=0.00
   OK compound_gear      corpi=1    35.2 x   35.1 x   25.0 mm     4.9 cm3  base Z=0.00
   OK cover              corpi=1    70.0 x  123.0 x   11.2 mm    28.8 cm3  base Z=0.00
   OK hall_plate         corpi=1    55.3 x   55.3 x    8.2 mm     9.6 cm3  base Z=0.00
   OK housing            corpi=1   205.0 x  196.6 x   72.0 mm   287.3 cm3  base Z=0.00
   OK magnet_flag        corpi=1    30.0 x   22.0 x    5.0 mm     1.9 cm3  base Z=0.00
   OK mono_arm           corpi=1    53.5 x  145.0 x   85.6 mm    69.2 cm3  base Z=0.00
   OK motor_bracket      corpi=1    42.0 x   45.2 x   19.7 mm     8.2 cm3  base Z=-0.00
   OK motor_pinion       corpi=1    12.8 x   12.6 x    9.5 mm     0.5 cm3  base Z=0.00
   OK output_gear        corpi=1    57.6 x   57.6 x   10.0 mm    15.8 cm3  base Z=0.00
   OK spacers            corpi=5    64.0 x    8.5 x   32.8 mm     2.1 cm3  base Z=0.00
   OK test_pin           corpi=2    85.2 x   23.5 x    6.3 mm     1.9 cm3  base Z=0.00
   OK test_shaft         corpi=1   100.0 x    5.9 x    5.3 mm     2.6 cm3  base Z=0.00
   -> tutti i pezzi sono solidi unici
   -> materiale totale (appoggi x2): 608 cm3

2) PEZZI FERMI MONTATI: compenetrazioni e luci
   housing        <-> cover          appoggio di faccia
   housing        <-> motor_bracket  appoggio di faccia
   housing        <-> hall_plate     appoggio di faccia
   housing        <-> spacers        appoggio di faccia
   housing        <-> bay_lid        appoggio di faccia
   housing        <-> bay_tray       appoggio di faccia
   housing        <-> output_gear    luce 2.20 mm
   housing        <-> compound_gear  luce 4.71 mm
   housing        <-> magnet_flag    luce 6.00 mm
   cover          <-> motor_bracket  luce 4.00 mm
   cover          <-> spacers        appoggio di faccia
   cover          <-> bay_lid        appoggio di faccia
   cover          <-> compound_gear  luce 3.19 mm
   cover          <-> motor_pinion   luce 5.50 mm
   motor_bracket  <-> compound_gear  luce 1.98 mm
   motor_bracket  <-> motor_pinion   luce 2.78 mm
   motor_bracket  <-> motor_dummy    appoggio di faccia
   hall_plate     <-> spacers        luce 1.75 mm
   hall_plate     <-> magnet_flag    luce 2.50 mm
   spacers        <-> output_gear    appoggio di faccia
   spacers        <-> compound_gear  luce 1.20 mm
   spacers        <-> magnet_flag    appoggio di faccia
   bay_lid        <-> bay_tray       appoggio di faccia
   output_gear    <-> compound_gear  ingranano (luce minima 0.10 mm)
   compound_gear  <-> motor_pinion   ingranano (luce minima 0.00 mm)
   compound_gear  <-> motor_dummy    luce 0.37 mm
   -> nessuna compenetrazione

3) CORSA COMPLETA 0 -> -270 gradi
      luce minima bandierina - piastra sensori        2.50 mm  (a -87 gradi)
      luce minima braccio - appoggi                  43.90 mm  (a -264 gradi)
      luce minima braccio - bay_lid                  82.26 mm  (a -270 gradi)
      luce minima braccio - cover                    72.00 mm  (a 0 gradi)
      luce minima braccio - housing                   8.00 mm  (a -48 gradi)
      luce minima braccio - motor_bracket            56.31 mm  (a -261 gradi)
      luce minima braccio - tubo                     36.50 mm  (a -270 gradi)
      luce minima tappo - appoggi                    10.83 mm  (a -267 gradi)
      luce minima tappo - bay_lid                    14.93 mm  (a -270 gradi)
      luce minima tappo - cover                      51.26 mm  (a 0 gradi)
      luce minima tappo - housing                     7.50 mm  (a -270 gradi)
      luce minima tappo - motor_bracket              44.54 mm  (a 0 gradi)
      luce minima tappo - tubo                       39.50 mm  (a -270 gradi)
   (tappo - appoggi e' escluso a fine corsa: li' il tappo ci appoggia)

4) PARCHEGGIO (-270 gradi)
   faccia inferiore del tappo: Y = 220.5 mm
   sommita' degli appoggi:     Y = 218.5 mm  (+2 mm di EVA = appoggio)
   coperchio vano elettronica: Y = 213.0 mm  -> luce 7.5 mm

5) EXTRACORSA (sensore OPEN guasto)
   corsa nominale 22928 passi, MAX_MOVE_STEPS 24100 -> arresto a -283.8 gradi
   oltre i -270 gradi il tappo e' gia' sugli appoggi: il motore si ferma
   contro di loro (il 28BYJ in stallo non si danneggia) e il firmware
   lo spegne al piu' tardi a MAX_MOVE_STEPS, segnalando lo stato 3.

======================================================================

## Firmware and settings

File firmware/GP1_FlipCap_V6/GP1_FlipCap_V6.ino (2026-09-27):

// SPDX-License-Identifier: CERN-OHL-S-2.0
// Copyright (C) 2026 Johannes1979I
/*
  GP1 FlipCap V6 - firmware
  Tappo motorizzato a braccio singolo, ribaltamento di 270 gradi.

  Hardware: Arduino Nano (ATmega328P) + 28BYJ-48 5 V + scheda ULN2003
            + 2 sensori Hall A3144 (CLOSED e OPEN)
  Riduzione: riduttore interno del 28BYJ + treno stampato 15:1
  Protocollo: emula l'Alnitak Remote Dust Cover (product ID 98), quindi
              funziona con il driver INDI "Flip Flat" (indi_flipflat) e con
              qualunque software che parli il protocollo Alnitak.
  Seriale: 9600 8N1, comandi terminati da LF.

  COLLEGAMENTI
    D2 D3 D4 D5  -> IN1 IN2 IN3 IN4 della scheda ULN2003
    D10          <- uscita del sensore Hall CLOSED (tappo chiuso)
    D11          <- uscita del sensore Hall OPEN   (tappo parcheggiato)
    I sensori sono attivi bassi: il Nano usa le sue resistenze di pull-up.

  COME SI MUOVE
  - Full-step con due fasi sempre eccitate: e' il modo con piu' coppia.
  - Rampa di accelerazione in partenza, poi ~417 passi al secondo.
  - Ci si ferma sul sensore del lato verso cui si va. Il sensore vale solo
    se letto attivo quattro volte di fila (antirimbalzo).
  - Due protezioni se un sensore non scatta: un limite di passi (circa il
    5% oltre la corsa nominale) e un limite di tempo. In quel caso lo
    stato diventa 3 (errore) e il motore si spegne.
  - A motore fermo le bobine sono spente: non scaldano e non consumano.

  ALIMENTAZIONE
  - Il motore prende i 5 V dal convertitore, non dal Nano: sotto sforzo il
    28BYJ assorbe fino a ~250 mA e la porta USB del PC non va caricata.
  - Il GND del convertitore e quello del Nano devono essere in comune.
*/

#include <Arduino.h>

static const uint32_t BAUD_RATE = 9600;
static const uint8_t MOTOR_PINS[4] = {2, 3, 4, 5};
static const uint8_t HALL_CLOSED_PIN = 10;
static const uint8_t HALL_OPEN_PIN   = 11;

// Mettere a true se dopo il montaggio OPEN/CLOSE risultano invertiti.
static const bool MOTOR_REVERSED = false;

// --- Budget di movimento -------------------------------------------------
// 28BYJ-48: 2038 full-step per giro d'uscita. Con la riduzione stampata 15:1
// un giro del braccio sono 30570 full-step, quindi i 270 gradi della corsa
// sono 22.928 passi: circa 55 secondi a regime.
static const uint32_t STEP_INTERVAL_US  = 2400;  // regime: ~417 full-step/s
static const uint32_t START_INTERVAL_US = 6000;  // partenza della rampa
static const uint32_t RAMP_STEPS        = 400;   // lunghezza rampa (~0,7 s)

// Con 270 gradi la corsa dura circa 55 s, cioe' PIU' dei 30 s dopo i quali il
// driver indi_flipflat rimanda il comando:
//     IEAddTimer(30000, parkTimeoutHelper, this);
//     LOG_WARN("Parking cap timed out. Retrying..."); ParkCap();
// Non e' un problema di per se': il comando ripetuto e' nella stessa direzione
// del movimento in corso e startMotion() lo ignora (vedi la guardia piu'
// sotto), quindi la corsa prosegue e finisce normalmente. Senza quella guardia
// il comando ripetuto azzererebbe moveSteps e raddoppierebbe di fatto il
// limite di extracorsa.
static const uint32_t MOVE_TIMEOUT_MS   = 70000; // deve stare sopra i 55 s di corsa

// Corsa nominale 270 gradi = 22.928 passi full-step (2038 x 15 x 0,75).
// Oltre il fine corsa il tappo non ha piu' niente da colpire: va semplicemente
// in appoggio sui supporti, quindi il limite serve solo a non far macinare il
// motore all'infinito se il sensore OPEN non scatta.
static const uint32_t MAX_MOVE_STEPS    = 24100;  // ~5% oltre i 22.928 nominali

static const uint8_t PRODUCT_ID = 98;

// Codifica stato INDI FlipFlat in *S98xyz:
//   x motore: 0 fermo / 1 in moto
//   y luce:   sempre 0 (product 98 = dust cover, niente pannello)
//   z tappo:  0 intermedio, 1 chiuso, 2 aperto, 3 timeout/errore
static uint8_t coverStatus = 0;
static bool moving = false;
static int8_t moveDirection = 0;   // +1 OPEN, -1 CLOSE
static uint32_t moveStartMs = 0;
static uint32_t moveSteps = 0;
static uint32_t lastStepUs = 0;
static uint32_t stepInterval = STEP_INTERVAL_US;
static uint8_t phase = 0;

// Full-step, 2 fasi sempre eccitate.
static const uint8_t FULLSTEP[4][4] = {
  {1, 1, 0, 0},
  {0, 1, 1, 0},
  {0, 0, 1, 1},
  {1, 0, 0, 1}
};

static char rx[16];
static uint8_t rxLen = 0;

void setMotorPhase(uint8_t p)
{
  for (uint8_t i = 0; i < 4; ++i)
    digitalWrite(MOTOR_PINS[i], FULLSTEP[p & 3][i] ? HIGH : LOW);
}

void motorOff()
{
  for (uint8_t i = 0; i < 4; ++i) digitalWrite(MOTOR_PINS[i], LOW);
}

// Antirimbalzo: il finecorsa vale solo se letto basso 4 volte di fila.
static bool hallActive(uint8_t pin)
{
  for (uint8_t i = 0; i < 4; ++i) {
    if (digitalRead(pin) != LOW) return false;
    delayMicroseconds(60);
  }
  return true;
}

bool closedActive() { return hallActive(HALL_CLOSED_PIN); }
bool openActive()   { return hallActive(HALL_OPEN_PIN); }

// Intervallo corrente: rampa lineare da START_INTERVAL_US a STEP_INTERVAL_US.
static uint32_t rampInterval(uint32_t n)
{
  if (n >= RAMP_STEPS) return STEP_INTERVAL_US;
  uint32_t span = START_INTERVAL_US - STEP_INTERVAL_US;
  return START_INTERVAL_US - (span * n) / RAMP_STEPS;
}

void determineInitialState()
{
  delay(20);
  bool c = closedActive(), o = openActive();
  if (c && !o) coverStatus = 1;
  else if (o && !c) coverStatus = 2;
  else coverStatus = 0;
}

void stopMotion(uint8_t state)
{
  moving = false;
  moveDirection = 0;
  coverStatus = state;
  motorOff();
}

void startMotion(int8_t direction)
{
  int8_t d = (direction > 0) ? 1 : -1;

  // Comando ripetuto nella stessa direzione mentre siamo gia' in movimento:
  // e' il retry del driver INDI dopo 30 s. Va ignorato, altrimenti azzera i
  // contatori di corsa e con loro il limite di extracorsa.
  if (moving && moveDirection == d) return;

  if (direction > 0 && openActive())   { stopMotion(2); return; }
  if (direction < 0 && closedActive()) { stopMotion(1); return; }

  moving = true;
  moveDirection = d;
  coverStatus = 0;
  moveStartMs = millis();
  moveSteps = 0;
  stepInterval = START_INTERVAL_US;
  lastStepUs = micros();
}

void serviceMotion()
{
  if (!moving) return;

  if (moveDirection > 0 && openActive())   { stopMotion(2); return; }
  if (moveDirection < 0 && closedActive()) { stopMotion(1); return; }

  if ((millis() - moveStartMs) >= MOVE_TIMEOUT_MS || moveSteps >= MAX_MOVE_STEPS) {
    stopMotion(3);
    return;
  }

  uint32_t now = micros();
  if ((uint32_t)(now - lastStepUs) < stepInterval) return;
  lastStepUs += stepInterval;

  int8_t d = moveDirection;
  if (MOTOR_REVERSED) d = -d;
  phase = (uint8_t)((phase + d + 4) & 3);
  setMotorPhase(phase);

  ++moveSteps;
  stepInterval = rampInterval(moveSteps);
}

void replySimple(char op)
{
  Serial.print('*'); Serial.print(op);
  if (PRODUCT_ID < 10) Serial.print('0');
  Serial.print(PRODUCT_ID); Serial.println("000");
}

void replyStatus()
{
  Serial.print("*S");
  if (PRODUCT_ID < 10) Serial.print('0');
  Serial.print(PRODUCT_ID);
  Serial.print(moving ? '1' : '0');
  Serial.print('0');
  Serial.println((char)('0' + coverStatus));
}

void replyVersion()
{
  Serial.print("*V");
  if (PRODUCT_ID < 10) Serial.print('0');
  Serial.print(PRODUCT_ID); Serial.println("160");
}

void replyBrightness()
{
  Serial.print("*J");
  if (PRODUCT_ID < 10) Serial.print('0');
  Serial.print(PRODUCT_ID); Serial.println("000");
}

void handleCommand(const char *cmd)
{
  if (cmd[0] != '>' || strlen(cmd) < 2) return;
  switch (cmd[1]) {
    case 'P': replySimple('P'); break;
    case 'O': startMotion(+1); replySimple('O'); break;
    case 'C': startMotion(-1); replySimple('C'); break;
    case 'S': replyStatus(); break;
    case 'V': replyVersion(); break;
    case 'J': replyBrightness(); break;
    case 'B': replySimple('B'); break;
    case 'L': replySimple('L'); break;
    case 'D': replySimple('D'); break;
    default: break;
  }
}

void serviceSerial()
{
  while (Serial.available()) {
    char c = (char)Serial.read();
    if (c == '\r') continue;
    if (c == '\n') {
      rx[rxLen] = '\0';
      if (rxLen) handleCommand(rx);
      rxLen = 0;
    } else if (rxLen < sizeof(rx) - 1) {
      rx[rxLen++] = c;
    } else {
      rxLen = 0;
    }
  }
}

void setup()
{
  for (uint8_t i = 0; i < 4; ++i) pinMode(MOTOR_PINS[i], OUTPUT);
  motorOff();
  pinMode(HALL_CLOSED_PIN, INPUT_PULLUP);
  pinMode(HALL_OPEN_PIN, INPUT_PULLUP);
  Serial.begin(BAUD_RATE);
  determineInitialState();
}

void loop()
{
  serviceSerial();
  serviceMotion();
}

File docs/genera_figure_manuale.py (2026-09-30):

#!/usr/bin/env python3
# SPDX-License-Identifier: CERN-OHL-S-2.0
# Copyright (C) 2026 Johannes1979I
"""
GP1 FlipCap V6 - genera le figure del manuale.

Produce in docs/manuale/:
  - i render OpenSCAD dei passi di montaggio, con le etichette gia' messe
  - gli schemi disegnati (corsa, albero, motore, vano, cablaggio, cinghie)

Uso:  python docs/genera_figure_manuale.py
Serve: matplotlib, pillow, numpy e OpenSCAD (variabile OPENSCAD se non e' nel PATH).

Le etichette sui render sono posizionate proiettando i punti 3D con la
stessa camera ortografica usata da OpenSCAD (campo visivo 22,5 gradi), per
cui restano giuste anche se si cambiano i parametri del modello.
"""
import os
import re
import shutil
import subprocess
import sys
import tempfile
from concurrent.futures import ThreadPoolExecutor

import numpy as np
import matplotlib
matplotlib.use("Agg")
import matplotlib.pyplot as plt
from matplotlib.patches import Circle, FancyBboxPatch, Rectangle, Polygon
from PIL import Image

ROOT = os.path.dirname(os.path.dirname(os.path.abspath(__file__)))
OUT = os.path.join(ROOT, "docs", "manuale")
SCAD = os.path.join(ROOT, "gp1_flipcap_V6.scad")
WORK = os.path.join(tempfile.gettempdir(), "gp1_v6_figure")

INK, ACC, WARN = "#1b2b3a", "#1f6fb2", "#c0392b"
RED, BLK, BLU, GRN, ORA, VIO = "#c0392b", "#2c3e50", "#1f6fb2", "#1e8449", "#e08214", "#7d3c98"
GREY = "#5a6b7a"


def openscad_exe():
    for c in (os.environ.get("OPENSCAD"), shutil.which("openscad"),
              r"C:\Program Files\OpenSCAD\openscad.exe",
              "/Applications/OpenSCAD.app/Contents/MacOS/OpenSCAD", "/usr/bin/openscad"):
        if c and os.path.exists(c):
            return c
    sys.exit("OpenSCAD non trovato: imposta la variabile d'ambiente OPENSCAD")


OPENSCAD = openscad_exe()


# ------------------------------------------------------------ parametri
def read_params():
    names = ["hinge_y", "hinge_z", "arm_x", "arm_dz", "cap_d", "ota_d", "open_angle",
             "box_x0", "box_x1", "box_y0", "box_y1", "box_z0", "box_z1",
             "bay_y0", "bay_y1", "bay_z0", "bay_z1", "rest_z", "front_saddle_z",
             "rear_saddle_z", "saddle_x1", "compound_yz", "motor_yz", "can_yz",
             "byj_ears", "byj_w", "flag_x", "left_seat_x0", "left_seat_x1",
             "cover_seat_x0", "cover_seat_x1", "spacer_list", "nano_pos", "nano_size",
             "nano_holes", "buck_pos", "buck_size", "buck_holes", "uln_pos", "uln_size",
             "uln_holes", "usb_hole", "jack_yz", "cable_slot", "compound_x", "hall_standoff",
             "hall_screw_a", "hall_screw_r", "magnet_r", "cav_x0", "mb_screws",
             "hall_leg_turn", "hall_cap_side", "hall_wire_u0", "hall_cap_u", "hall_cap_v",
             "bay_bosses", "rest_pad", "cap_thickness", "cover_t"]
    with open(os.path.join(WORK, "probe.scad"), "w") as f:
        f.write("include <modello.scad>\n")
        for n in names:
            f.write('echo(str("P %s=", %s));\n' % (n, n))
    echo = os.path.join(WORK, "probe.echo")
    subprocess.run([OPENSCAD, "-o", echo, "-D", 'part="none"', "probe.scad"],
                   cwd=WORK, capture_output=True)
    txt = open(echo, errors="ignore").read()
    P = {}
    for n, v in re.findall(r'ECHO: "P (\w+)=(.*)"\s*$', txt, re.M):
        v = v.replace('\\"', '"')
        try:
            P[n] = eval(v.replace("true", "True").replace("false", "False"))
        except Exception:
            P[n] = v
    missing = [n for n in names if n not in P]
    if missing:
        sys.exit("parametri non letti: %s" % missing)
    return P


# ------------------------------------------------------------ render 3D
FOV_TAN = np.tan(np.radians(22.5 / 2))


def to_view(p):
    """Il wrapper ruota il modello di +90 gradi attorno a X: Y del modello in alto."""
    x, y, z = p
    return np.array([x, -z, y], float)


class Cam:
    def __init__(self, eye, center, size):
        self.eye, self.center = np.array(eye, float), np.array(center, float)
        self.W, self.H = size
        d = self.center - self.eye
        self.dist = np.linalg.norm(d)
        d /= self.dist
        r = np.cross(d, [0, 0, 1])
        self.right = r / np.linalg.norm(r)
        self.up = np.cross(self.right, d)
        self.scale = (self.H / 2) / (self.dist * FOV_TAN)

    def arg(self):
        return "--camera=%s" % ",".join("%.3f" % v for v in (*self.eye, *self.center))

    def px(self, p_model):
        q = to_view(p_model) - self.center
        return (self.W / 2 + q.dot(self.right) * self.scale,
                self.H / 2 - q.dot(self.up) * self.scale)


def scad_scene(items):
    """items: righe OpenSCAD gia' pronte da mettere dentro la rotazione."""
    return ("include <modello.scad>\n$fn=72;\n" + BRG_MODULE + "\nrotate([90,0,0]){\n" +
            "\n".join("    " + s for s in items) + "\n}\n")


def render(name, items, cam, labels=(), title=None, crop=True):
    scad = os.path.join(WORK, name.replace(".png", ".scad"))
    with open(scad, "w") as f:
        f.write(scad_scene(items))
    raw = os.path.join(WORK, name)
    r = subprocess.run([OPENSCAD, "-o", raw, "--imgsize=%d,%d" % (cam.W, cam.H),
                        cam.arg(), "--projection=o", "--colorscheme=Tomorrow",
                        "-D", 'part="none"', os.path.basename(scad)],
                       cwd=WORK, capture_output=True)
    if r.returncode != 0 or not os.path.exists(raw):
        print("   %-28s FALLITO" % name)
        return
    img = np.asarray(Image.open(raw).convert("RGB"))
    annotate(img, cam, labels, os.path.join(OUT, name), title, crop)
    print("   %-28s ok" % name)


def _label_boxes(cam, labels):
    """Per ogni etichetta: punto indicato, centro del testo, mezze misure del riquadro."""
    out = []
    for text, p3, off, *rest in labels:
        ax_, ay_ = cam.px(p3)
        lines = text.split("\n")
        hw = 5.2 * max(len(l) for l in lines) + 12
        hh = 11 * len(lines) + 8
        out.append((text, (ax_, ay_), (ax_ + off[0], ay_ + off[1]), hw, hh, rest[0] if rest else INK))
    return out
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

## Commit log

2026-09-21 GP1 FlipCap V4.2
    Revisione completa della V4.1, che aveva tre difetti bloccanti trovati
    campionando le mesh STL reali:
    - housing.stl conteneva due solidi separati: la piastra di supporto del
    28BYJ-48 era sospesa a 12,45 mm da qualunque parete, quindi il motore
    non aveva alcun punto di fissaggio. Ora e' un pezzo a se', motor_bracket,
    che si autoallinea su soffitto, parete sinistra e boss del coperchio.
    - Il monobraccio compenetrava l'housing su tutta la corsa (mozzo dentro il
    boss del cuscinetto, nervature dentro la parete, flangia dentro lo
    spigolo della scatola). Ridisegnato: 0 punti di compenetrazione, luce
    minima 2,00 mm.
    - A -105 gradi il disco del tappo passava a 0,65 mm da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
    [BOM_elettronica.csv, BOM_meccanica.csv, GP1_electronics_box_MINI.stl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]
2026-09-21 Manuale generico, tappo da 3 mm, firmware compilato
    Manuale riscritto per chi costruisce da zero, non per chi viene dalla V4.1:
    - capitolo 0 con l'elenco completo dei dieci pezzi da stampare, volumi,
    filamento stimato, orientamento e supporti per ciascuno
    - tabella di scelta del materiale del tappo con il margine di coppia per
    altezza del tubo, che e' il vero criterio di scelta
    - capitolo su come adattare il progetto a un tubo di diametro diverso
    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
    [gp1_flipcap_V4_2.scad, lid_backplate.stl, mono_arm.stl]
2026-09-27 GP1 FlipCap V6: ribaltamento 270 gradi, elettronica integrata
    Il repository ora contiene solo la V6, completa per costruirla da zero.
    - gp1_flipcap_V6.scad riscritto: con F5 l'assieme mostra tutti i pezzi
    (prima gli interruttori show_* non erano definiti e si vedevano solo
    tappo e coperchio); ogni pezzo si esporta gia' orientato per la stampa.
    - Motore nella posizione reale: il 28BYJ-48 ha l'albero decentrato di
    8 mm e la staffa lo ignorava, il pignone non avrebbe ingranato. Treno
    ridisposto (composto a 15 gradi, motore a -13), fondo scatola -10 mm.
    - Foro del grano dell'ingranaggio di uscita spostato nel mozzo: prima
    cadeva sulla faccia e non poteva bloccare l'albero.
    - Albero di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
    [BOM_elettronica.csv, BOM_meccanica.csv, GP1_electronics_box_MINI.stl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]
2026-09-27 Bandierina V4.1 da ristampare: la tasca del magnete e' chiusa
    Nella V4.1 la tasca del magnete stava al centro dello spessore della
    bandierina, chiusa su entrambe le facce: il magnete non si puo' inserire.
    README e appendice F del manuale ora lo dicono; la bandierina della V6
    ha la tasca aperta verso i sensori.
    [gp1_flipcap_V6.scad]
2026-09-27 Logo dell'Osservatorio Jupiter e montaggio della meccanica nel manuale
    - housing: logo inciso per 1 mm sulla faccia anteriore del riduttore
    (Giove con bande e Grande Macchia Rossa, satelliti medicei, nome).
    logo=false per la scatola liscia; carattere Liberation Sans, incluso
    in OpenSCAD, cosi' l'STL esce uguale su ogni PC
    - manuale: esploso del riduttore, tabella di come e' tenuto ogni pezzo,
    riga "Ti serve" con pezzi e viti in ogni passo, nota sulla testa della
    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
    [BOM_meccanica.csv, gp1_flipcap_V6.scad, housing.stl]
2026-09-28 Assi di prova in plastica: STL e appendice G del manuale
    - stl/test_shaft.stl e stl/test_pin.stl (facoltativi): albero di uscita
    e perno del composto in versione stampata, un decimo sotto il
    nominale, con un piano lungo tutto l'asse che li tiene sul piatto e fa
    da sede ai grani; il perno ha una ghiera elastica al posto del dado
    - manuale: nuova appendice G (impostazioni di stampa, prove possibili e
    no, perche' non sotto carico, come passare all'acciaio), riga nella
    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
    [gp1_flipcap_V6.scad, test_pin.stl, test_shaft.stl]
2026-09-29 Ingranaggi della prima versione: come riconoscerli
    La V4 originale aveva un treno diverso (pignoni da 12 denti, uscita piu'
    piccola) che non ingrana con gli interassi della V4.1 e della V6. Il
    manuale (appendice F) ora ha la tabella di denti e diametri giusti e
    l'avviso di non riusare quei pezzi e di non scalarli; stessa nota nel
    README.
2026-09-29 Pignone del motore con grano M3
    Denti larghi 5 mm, mozzo lungo dal lato del coperchio con un grano M3 x 5
    che stringe su un piano dell'albero del 28BYJ; foro scorrevole da 5,1 mm,
    niente piu' foro da limare a D. Manuale (A1, C7, tabella dei fissaggi,
    viteria) e distinta: i grani M3 x 5 diventano tre.
    [BOM_meccanica.csv, gp1_flipcap_V6.scad, motor_pinion.stl]
2026-09-30 Piastra sensori: cablaggio incassato fino al bordo
    I piedini degli A3144 non vanno piu' verso il centro, dove fra il boss del
    cuscinetto e la bandierina non c'era spazio per saldare. Da ogni sede parte
    un canale che arriva fino al bordo della piastra, con accanto l'incavo del
    condensatore da 100 nF: saldature, condensatore e fili restano sotto il
    piano su cui passa la bandierina e i fili escono di lato.
    - la corona esterna (r > 13,2) scende di 3 mm verso la parete per dare
    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
    [gp1_flipcap_V6.scad, hall_plate.stl]
2026-10-15 Firmware da osservatorio, porte fisse, angolari di fermo
    Firmware (provato sul prototipo all'osservatorio):
    - sensori su D6 (CLOSED) e D7 (OPEN); filtro di 20 ms sui finecorsa
    - risposte con solo LF: il driver indi_flipflat legge 8 byte esatti e con
    CR+LF falliva il ping ("Device ping failed / Unable to parse input")
    - oltre-corsa separato dopo lo scatto del sensore: apertura 2250 passi,
    chiusura 1400 (i sensori scattano ~17 gradi prima del magnete)
    - ordine delle fasi selezionabile (PHASE_ORDER), velocita' 2000 us/passo
    - comandi di diagnostica fuori protocollo: >N, >T, >K, >E, >F
    - .hex ricompilato
    tools/stk500.py: carica il .hex sul Nano senza avrdude (Raspberry).
    Angolari di fermo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
2026-10-15 Firmware: 7 gradi in piu' di oltre-corsa in apertura
    Sul tappo montato l'apertura restava corta: OVERRUN_OPEN_STEPS da 2250 a
    2844 passi (+594, circa 7 gradi all'albero). Chiusura invariata (1400).
    Caricato sul Nano del Pi EQ8 il 15/10/2026.
2026-10-15 Firmware: tolti i file intermedi della compilazione, resta solo il .hex
2026-10-15 Firmware: modalita' a passi fissi, sensori ignorati
    Il 15/10/2026 l'alimentazione dei sensori Hall e' risultata instabile: senza
    corrente gli A3144 tirano D6 e D7 a massa e il firmware credeva di essere gia'
    chiuso e gia' aperto (il motore "vibrava" fra comando e arresto). In attesa
    della riparazione:
    - STEPS_ONLY = true: apertura = OPEN_STEPS passi dalla posizione chiusa,
    chiusura = ritorno a zero; i sensori non vengono letti
    - posizione, stato e passi di apertura in EEPROM: il reset che Ekos fa a ogni
    connessione non fa perdere la posizione
    - OPEN_STEPS = 23755 (tarato sul tappo montato: +5 gradi su 23330)
    - >Exxxxx cambia e salva i passi di apertura, >Z dichiara chiusa la posizione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
